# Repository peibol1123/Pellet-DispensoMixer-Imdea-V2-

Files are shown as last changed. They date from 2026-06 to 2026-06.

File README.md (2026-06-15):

# Pellet DispensoMixer V2

Developed at IMDEA Materials Institute.

<p align="center">
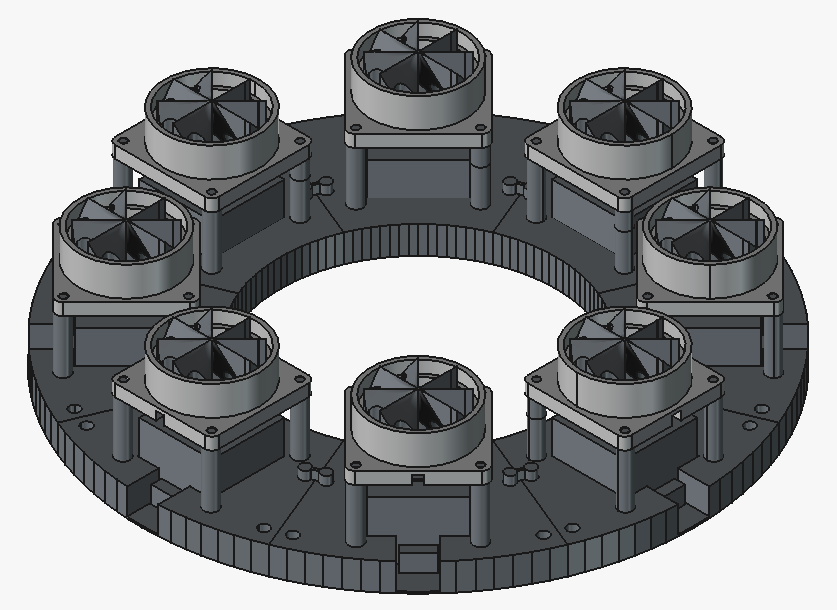
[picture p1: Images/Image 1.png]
  
</p>

## Project Overview

The Pellet DispensoMixer V2 is an updated and improved version of the original Pellet DispensoMixer developed at IMDEA. The main objective of this redesign was to increase system reliability, simplify assembly and maintenance procedures, and improve the overall integration of the platform.

The new version replaces the previous actuation system with NEMA 17 stepper motors and consolidates the electronic architecture into a single control board, reducing wiring complexity and improving maintainability.

This repository contains the complete design package generated during the development of the project, including CAD models, manufacturing files, electrical schematics, and supporting documentation.

## Key Features

- NEMA 17 stepper motor actuation.
- Single integrated control PCB: BIGTREETECH Octopus V1.1
- Modular and maintainable mechanical architecture.
- Complete CAD documentation.
- Manufacturing-ready 3D models.
- Electrical schematics and wiring documentation.
- Improved assembly workflow.
- Open and editable design files.

## Improvements Over the Original Pellet DispensoMixer

This project represents a significant redesign of the original Pellet DispensoMixer platform.

| Feature | Original Version | V2 |
|---|---|---|
| Actuation System | 28BYJ-48 unipolar geared stepper motor | NEMA 17 stepper motors |
| Electronics | 8x Arduino UNO | Single integrated PCB |
| Assembly | More complex integration | Tool-free cascade assembly with vertically stacked components and sequential insertion |
| Reliability | Baseline performance | Improved robustness |

## Bill of Materials

| Component | Quantity |
|---|---|
| NEMA 17 Stepper Motor | 8 |
| A4988 Stepper Motor Driver | 8 |
| BTT Octopus Pro Main Control Board | 1 |
| Power Supply | 1 |
| 3D Printed Components |  |
| Feed Ramp | 8 |
| Module Coupling Pin | 8 |
| Rotor Mount | 8 |
| Rotor | 8 |
| Structural Frame | 8 |
## Repository Structure

```text
CAD/
├── Assembly/
  ├── FreeCAD/
  ├── STEP/
├── Parts/
  ├── FreeCAD/
  ├── STEP/

Electronics/
├── Schematics/
├── PCB/
└── Wiring/

Images/
├── FinalAssembly.png
└── PrototypePhotos/

Documentation/
└── AdditionalFiles/
```
## Assembly Instructions

The Pellet DispensoMixer V2 follows a screwless cascade assembly method. Each module is inserted vertically on top of the previous component, using the geometry of the base to guide the assembly.

The motor module is first positioned onto the base structure. The upper rotor mount is then inserted above the motor, aligning the central shaft and the surrounding guide columns. Finally, the rotor is aligned on top of the cylindrical chamber and inserted onto the motor shaft.
<p align="center">
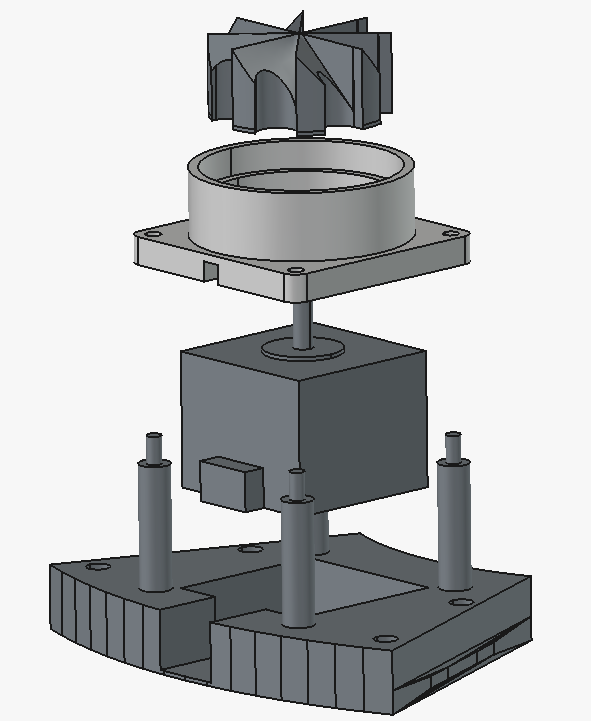
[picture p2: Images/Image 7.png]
  
</p>
Module-to-module alignment is achieved through a locating pin.
<p align="center">
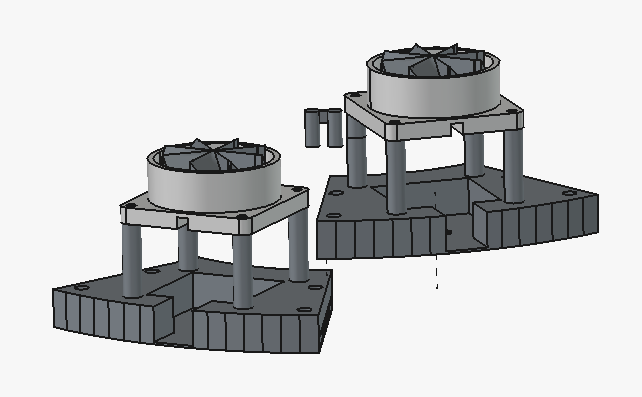
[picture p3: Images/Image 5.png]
  
</p>
This approach reduces the need for additional fasteners, simplifies the assembly process, and makes the system easier to disassemble, inspect, and maintain.

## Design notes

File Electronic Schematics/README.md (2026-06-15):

# Electronic Schematics

This folder contains the electronic wiring documentation for the Pellet DispensoMixer V2.

The electronic system is based on a **BIGTREETECH Octopus Pro V1.1** main control board, **A4988 stepper motor drivers**, **NEMA 17 stepper motors**, an external power supply, and an **ST-LINK/V2** programmer for SWD programming.

The objective of this documentation is to make the electronic assembly easier to reproduce, inspect, modify, and maintain.

---

## Main Components

| Component | Function |
| --- | --- |
| BIGTREETECH Octopus Pro V1.1 | Main control board |
| A4988 stepper motor drivers  | Motor driver modules |
| NEMA 17 stepper motors | Actuation of the dispensing modules |
| External power supply | Power input for the control board and motors |
| ST-LINK/V2 | SWD programming and debugging interface |

---

## Electronics Connections
### System Architecture

The electronics are centralized around the **BIGTREETECH Octopus Pro V1.1**, which acts as the main control board for the complete dispensing system.

```text
Power Supply
      │
      ▼
BIGTREETECH Octopus Pro V1.1
      │
      ├── A4988 Driver 1 ── NEMA 17 Motor 1
      ├── A4988 Driver 2 ── NEMA 17 Motor 2
      ├── A4988 Driver 3 ── NEMA 17 Motor 3
      ├── A4988 Driver 4 ── NEMA 17 Motor 4
      ├── A4988 Driver 5 ── NEMA 17 Motor 5
      ├── A4988 Driver 6 ── NEMA 17 Motor 6
      ├── A4988 Driver 7 ── NEMA 17 Motor 7
      └── A4988 Driver 8 ── NEMA 17 Motor 8
```

This architecture simplifies the wiring compared with the previous version of the system, since all motor control is handled from a single main board.

### Power Connection

The external power supply is connected to the main power input of the Octopus Pro board.

| Power Supply | Octopus Pro Connection |
| --- | --- |
| Positive output | `POWER +` / `VIN +` |
| Negative output | `POWER -` / `GND` |

Before powering the system, check:

* Correct polarity of the power input.
* Correct voltage level for the board and motor drivers.
* Correct motor power jumper configuration.
* No loose wires or accidental short circuits.

Do not power the board if the polarity or voltage configuration is uncertain.

### Stepper Driver and Stepper Motor Installation

Each motor has two internal coils. Before connecting the motors, identify the coil pairs using a multimeter in continuity mode.

Each **A4988 stepper motor driver** is inserted into one of the driver sockets of the Octopus Pro board.
<p align="center">
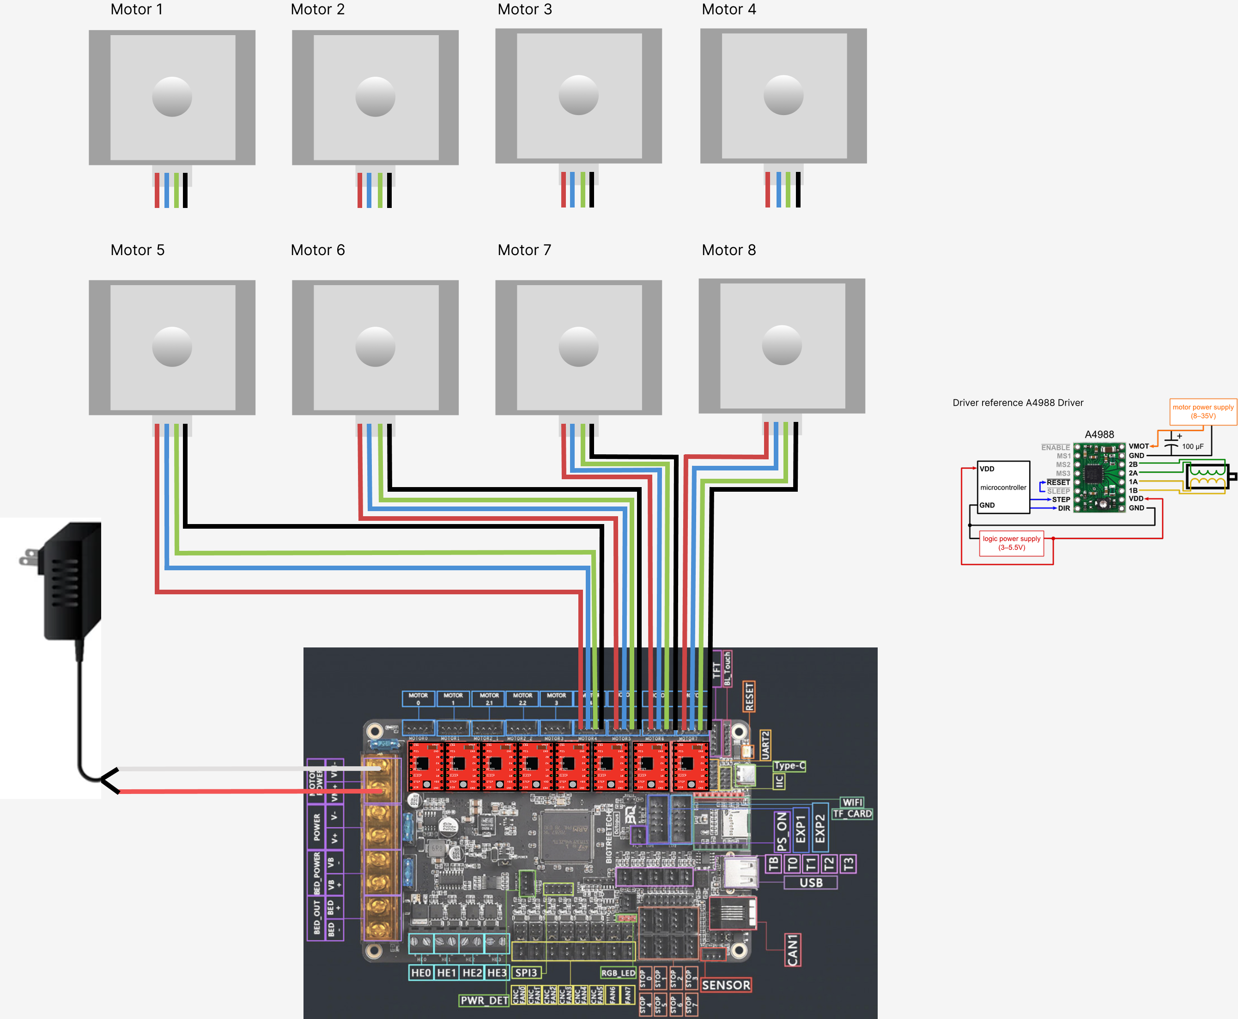
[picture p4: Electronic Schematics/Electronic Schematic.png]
Electronic Schematic
  
</p>
Important notes:

* Check the orientation of each A4988 driver before powering the board.
* Do not insert or remove drivers while the board is powered.
* Use heatsinks if the drivers operate for long periods or under high current.
* Adjust the current limit of each driver before continuous operation.

If a motor vibrates but does not rotate, the coil pairs may be incorrectly connected. If the motor rotates in the opposite direction, reverse the motor direction in firmware or swap one coil pair.

Do not connect or disconnect stepper motors while the board is powered

---

## ST-LINK/V2 Programming Connection

Before connecting the ST-LINK/V2 programmer, make sure that the required USB drivers are installed on the host computer.
The official ST-LINK drivers can be downloaded from [STMicroelectronics](https://www.st.com/en/development-tools/stsw-link009.html):

It is also recommended to install  [STM32CubeProgrammer](https://www.st.com/en/development-tools/stm32cubeprog.html), which provides the required tools for firmware upload, device detection, memory inspection, and debugging, however the firmware is gonna upload through Arduino Ide:

The following image provides a reference for the ST-LINK/V2 pinout.
<p align="center">
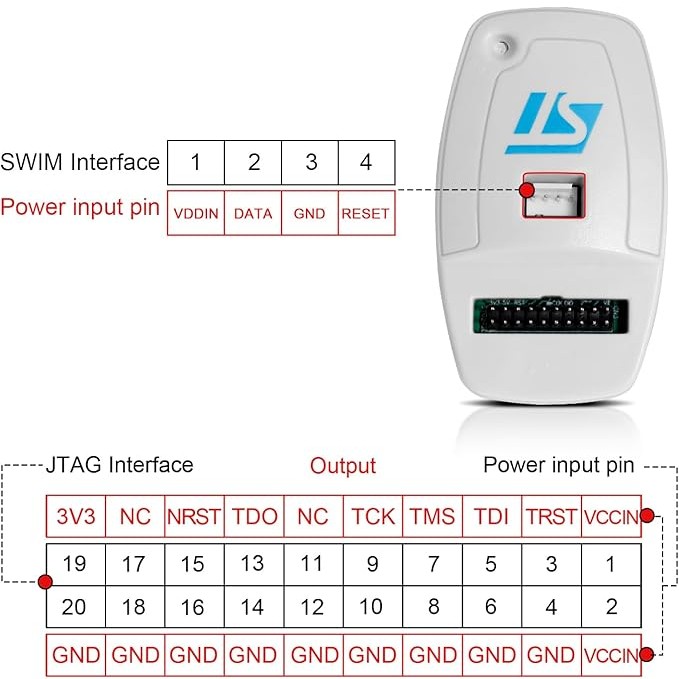
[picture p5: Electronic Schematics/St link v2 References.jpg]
ST Link V2 References
  
</p>
Recommended ST-LINK/V2 to Octopus Pro connection:

| ST-LINK/V2 20-pin Connector | Signal | Octopus Pro SWD Connector |
| --- | --- | --- |
| Pin 1 | `VCCIN` / target voltage reference | `3V3` |
| Pin 7 | `TMS` / `SWDIO` | `SWDIO` |
| Pin 9 | `TCK` / `SWCLK` | `SWCLK` |
| Pin 15 | `NRST` | `RST` |
| Pin 4 or any GND pin | `GND` | `GND` |

The `RST` connection is optional for basic SWD communication, but it is recommended because it allows the programmer to connect using hardware reset if needed.

The following image provides a reference for the BIGTREETECH Octopus Pro V1.1 pinout.
<p align="center">
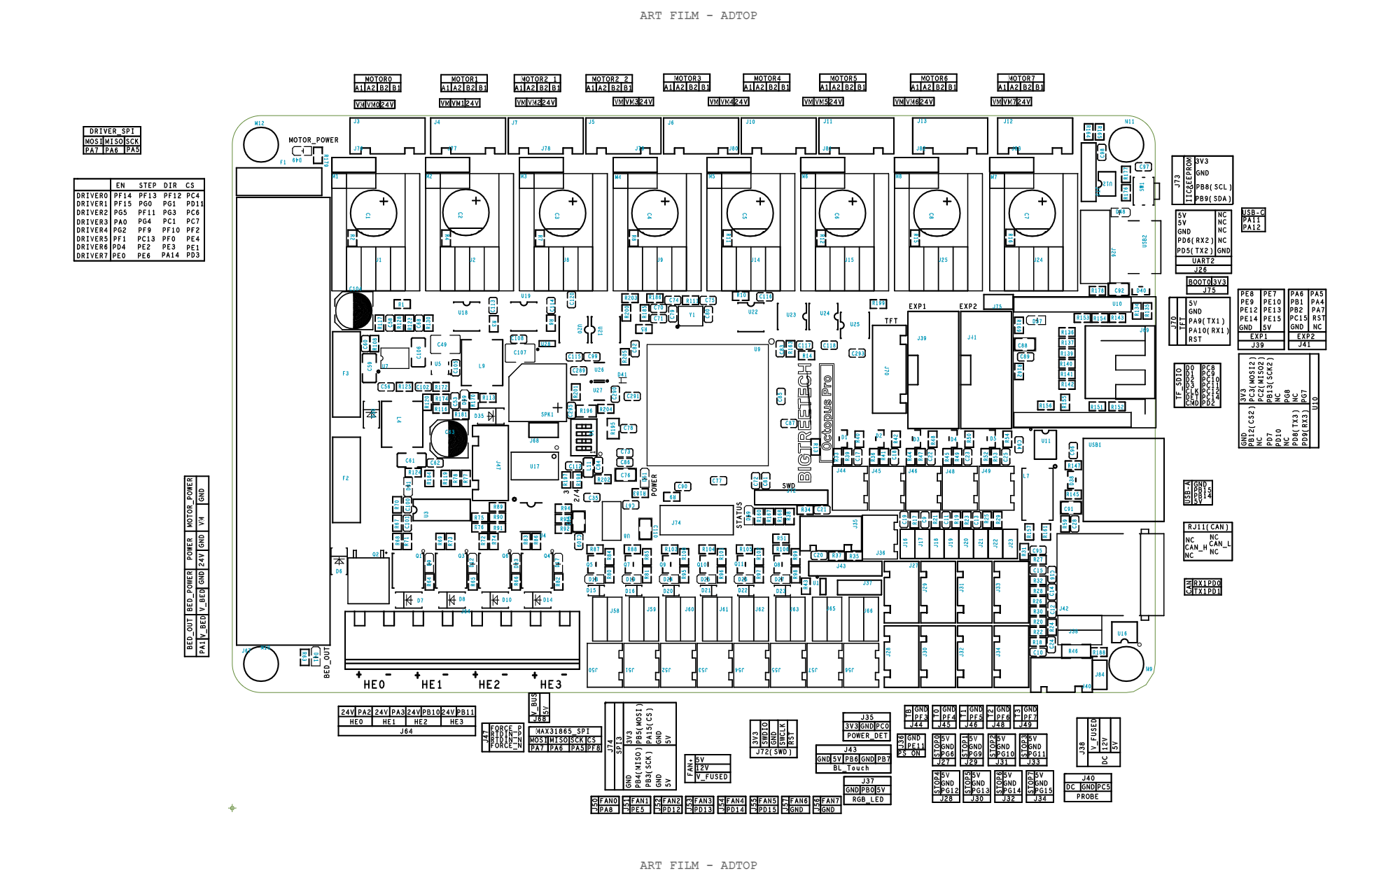
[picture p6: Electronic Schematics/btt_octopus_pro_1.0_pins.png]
BTT Octopus Pro V1.1 Pinout
  
</p>

## Suggested Cable Color Code

| Signal | Recommended Color |
| --- | --- |
| `3V3` / voltage reference | Red |
| `GND` | Brown |
| `SWDIO` | Orange |
| `SWCLK` | Yellow |
| `RST` | Green |

The following figure is provided as a reference for the wiring configuration.
<p align="center">
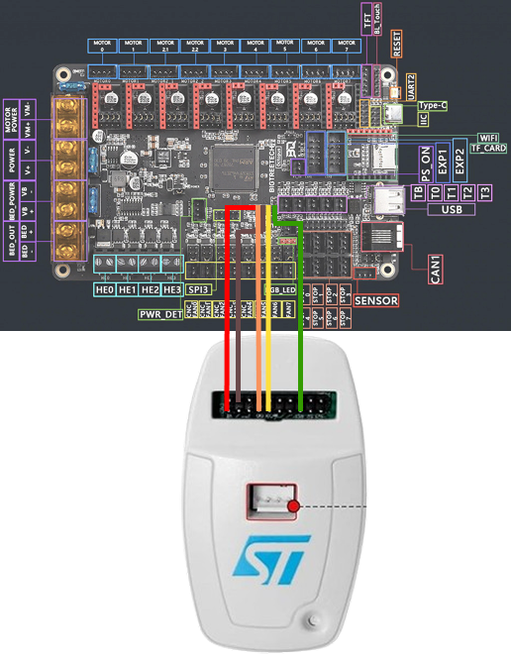
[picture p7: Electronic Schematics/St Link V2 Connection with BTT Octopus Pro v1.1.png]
ST-LINK V2 Connection with BTT Octopus Pro V1.1
  
</p>
---

## Electronics Assembly Procedure

1. Verify that the Octopus Pro board is powered off.
2. Insert the A4988 stepper motor drivers into the driver sockets.
3. Check the orientation of every A4988 driver.
4. Connect each NEMA 17 motor to its corresponding motor output.
5. Verify the coil pairs of each motor before powering the system.
6. Connect the external power supply to the Octopus Pro power input.
7. Connect the ST-LINK/V2 to the SWD connector if firmware programming is required.
8. Power the board and verify that no driver overheats.
9. Test each motor individually before running the full dispensing sequence.
10. If a motor moves in the wrong direction, correct the direction in firmware or swap one coil pair.

---

## Safety Notes

* Always disconnect power before modifying the wiring.
* Do not connect or disconnect motors while the board is powered.
* Do not insert or remove stepper drivers while the board is powered.
* Check the current limit of each A4988 driver before long operation.
* Verify power supply voltage and polarity before testing.
* Keep the board on a non-conductive surface during initial tests.
* If any component becomes excessively hot, power off the system immediately.

---

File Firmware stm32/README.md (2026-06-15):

# Firmware Compilation and Upload

This folder contains the firmware documentation for the Pellet DispensoMixer V2.

The firmware is compiled and uploaded using the **Arduino IDE**. The system is based on the **BIGTREETECH Octopus Pro V1.1** control board, which uses an STM32 microcontroller. For the initial board connection and firmware upload, an **ST-LINK/V2** programmer can be used through the SWD interface.

---

A detailed tutorial on configuring and programming STM32 microcontrollers with STM32Duino can be found in the following blog post:

[Luis Llamas – Programming STM32 with Arduino IDE and a USB-TTL Converter](https://www.luisllamas.es/programar-stm32-con-ide-de-arduino-y-conversor-usb-ttl/)

---

## Required Software

Before compiling or uploading the firmware, install the following software:

| Software | Purpose |
| --- | --- |
| Arduino IDE | Firmware development, compilation, and upload |
| STM32 MCU board package | STM32 board support inside Arduino IDE |
| ST-LINK/V2 drivers | Required for the computer to detect the ST-LINK programmer |
| STM32CubeProgrammer | Required for STM32 firmware upload and device detection |

The official ST-LINK/V2 drivers can be downloaded from [STMicroelectronics](https://www.st.com/en/development-tools/stsw-link009.html).

STM32CubeProgrammer can also be downloaded from [STMicroelectronics](https://www.st.com/en/development-tools/stm32cubeprog.html).

The Arduino IDE can be downloaded from [Arduino](https://www.arduino.cc/en/software).

---

## Installing STM32 Support in Arduino IDE

1. Open the Arduino IDE.
2. Go to:

```text
File → Preferences
```

3. In **Additional Boards Manager URLs**, add the following URL:

```text
https://github.com/stm32duino/BoardManagerFiles/raw/main/package_stmicroelectronics_index.json
```

4. Then go to:

```text
Tools → Board → Boards Manager
```

5. Search for:

```text
STM32 MCU based boards
```

6. Install the STM32 board package.

---

---

## ST-LINK/V2 Connection

The ST-LINK/V2 is used to connect to the STM32 microcontroller through the SWD interface.

The SWD wiring documentation is available in:

```text
Electronics Schematics/
```

## Compiling the Firmware

To compile the firmware in Arduino IDE:

```text
Sketch → Verify/Compile
```

or press:

```text
Ctrl + R
```

If the compilation is successful, the Arduino IDE will generate the firmware binary without errors.

---

## Uploading the Firmware Through Arduino IDE

To upload the firmware:

1. Connect the ST-LINK/V2 to the computer.
2. Connect the ST-LINK/V2 to the SWD connector of the Octopus Pro V1.1.
3. Power the Octopus Pro board using USB-C or the external power supply.
4. Open the firmware project in Arduino IDE.
5. Select the correct STM32 board configuration.
6. Select the upload method: St Link v2

After the upload is complete, the board should restart and run the uploaded firmware.

---

## Firmware Upload Workflow

```text
Install ST-LINK/V2 drivers
        ↓
Install STM32CubeProgrammer
        ↓
Install STM32 board package in Arduino IDE
        ↓
Open firmware in Arduino IDE
        ↓
Select STM32 board configuration
        ↓
Connect ST-LINK/V2 through SWD
        ↓
Compile firmware
        ↓
Upload firmware from Arduino IDE
```

---

## Troubleshooting

### The ST-LINK/V2 is not detected

Check that:

* The ST-LINK/V2 drivers are installed.
* The USB cable is working.
* The ST-LINK/V2 appears correctly in the device manager.
* STM32CubeProgrammer can detect the programmer.

### The board is not detected

Check that:

* The Octopus Pro board is powered.
* `3V3`, `GND`, `SWDIO`, and `SWCLK` are correctly connected.
* The SWD cable order is correct.
* A lower SWD frequency is selected.
* The `RST` wire is connected if using hardware reset.

### Upload fails

Check that:

* The correct board is selected in Arduino IDE.
* The selected upload method is `STM32CubeProgrammer (SWD)`.
* STM32CubeProgrammer is installed.
* The ST-LINK/V2 drivers are correctly installed.
* The board is not shorted or incorrectly powered.

### Compilation errors

Check that:

* The STM32 board package is installed.
* All required libraries are installed.
* The firmware files are in the correct folder.
* The selected board matches the STM32 microcontroller used by the Octopus Pro V1.1.

---

## Safety Notes

* Do not connect or disconnect wiring while the board is powered.
* Do not connect 5 V to the SWD connector.
* Verify the polarity of the external power supply before powering the board.
* Keep the board on a non-conductive surface during testing.
* If any component overheats, disconnect power immediately.
* Always verify the wiring before uploading or running the firmware.

---

## Notes

The Pellet DispensoMixer V2 firmware is developed and uploaded using the Arduino IDE. The ST-LINK/V2 programmer is used for SWD communication with the STM32 microcontroller, especially during initial configuration, firmware upload, or debugging.

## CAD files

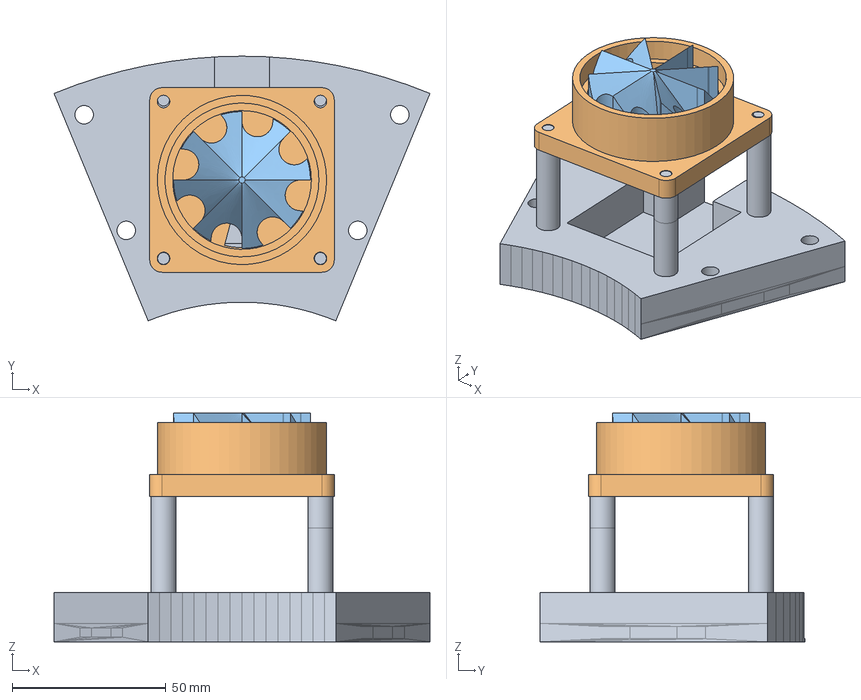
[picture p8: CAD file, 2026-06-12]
Pellet Dispensomixer V2 CAD/Assembly/Module SubAssembly/Module Pellet Dispensomixer V2.FCStd
122.2 x 86.0 x 74.3 mm
Structural Frame_001
Rotor Mount_001
Rotor_002

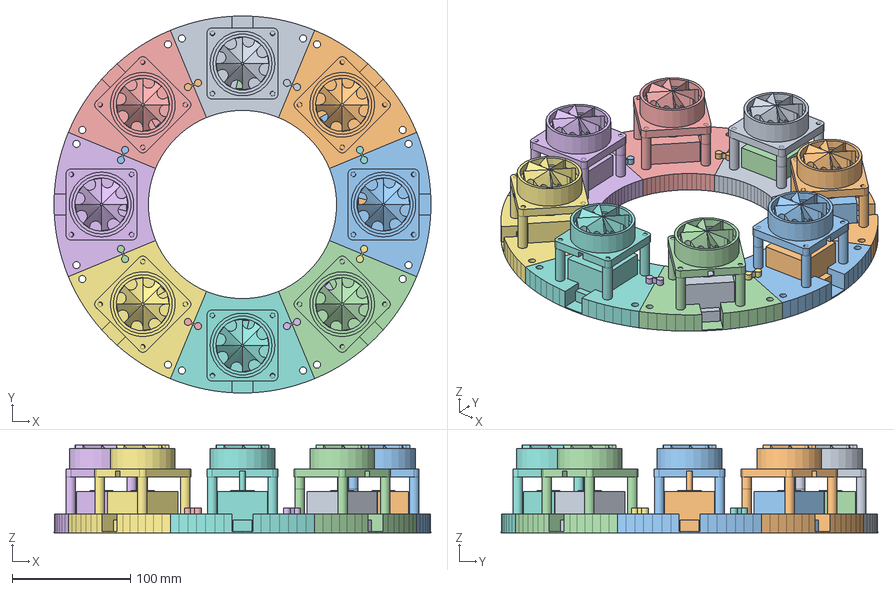
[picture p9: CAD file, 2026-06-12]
Pellet Dispensomixer V2 CAD/Assembly/Pellet Dispensomixer V2.FCStd
319.4 x 319.4 x 74.3 mm
Module Pellet Dispensomixer V2_001
Module Pellet Dispensomixer V2_003
Module Pellet Dispensomixer V2_004
Module Pellet Dispensomixer V2_006
Module Pellet Dispensomixer V2_007
Module Pellet Dispensomixer V2_008
Module Pellet Dispensomixer V2_009
Module Pellet Dispensomixer V2_010
Module Coupling Pin_001
Module Coupling Pin_002
Module Coupling Pin_003
Module Coupling Pin_004
Module Coupling Pin_005
Module Coupling Pin_006
Module Coupling Pin_007
Module Coupling Pin_008
Nema 17_003
Nema 17_004
Nema 17_005
Nema 17_006
Nema 17_007
Nema 17_008
Nema 17_009
Nema 17_010

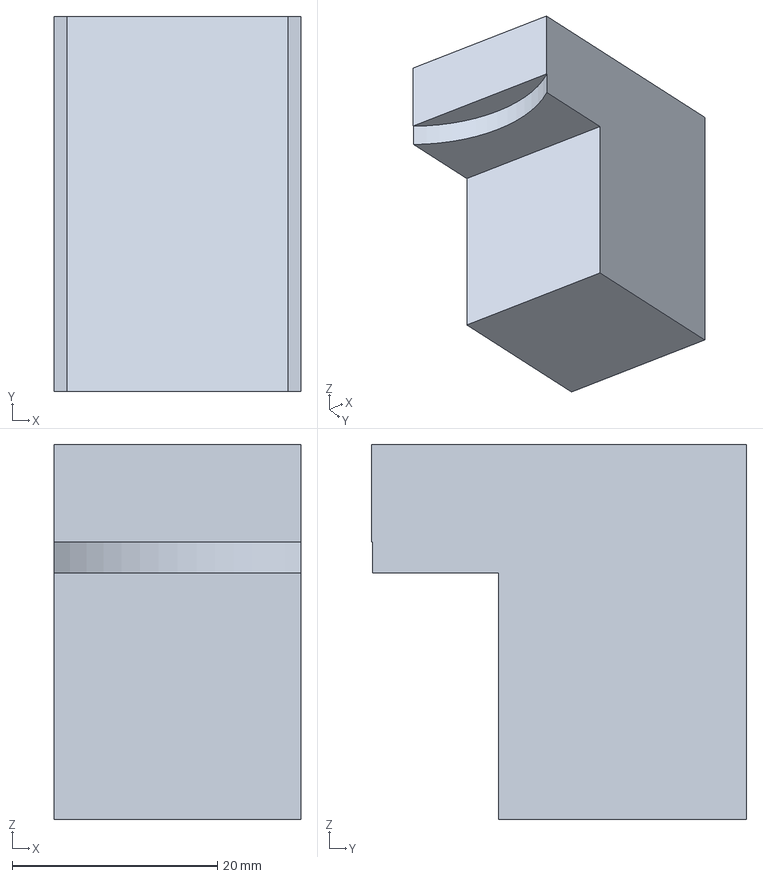
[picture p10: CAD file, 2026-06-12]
Pellet Dispensomixer V2 CAD/Parts/Feed Ramp/Feed Ramp.FCStd
24.0 x 36.5 x 36.5 mm

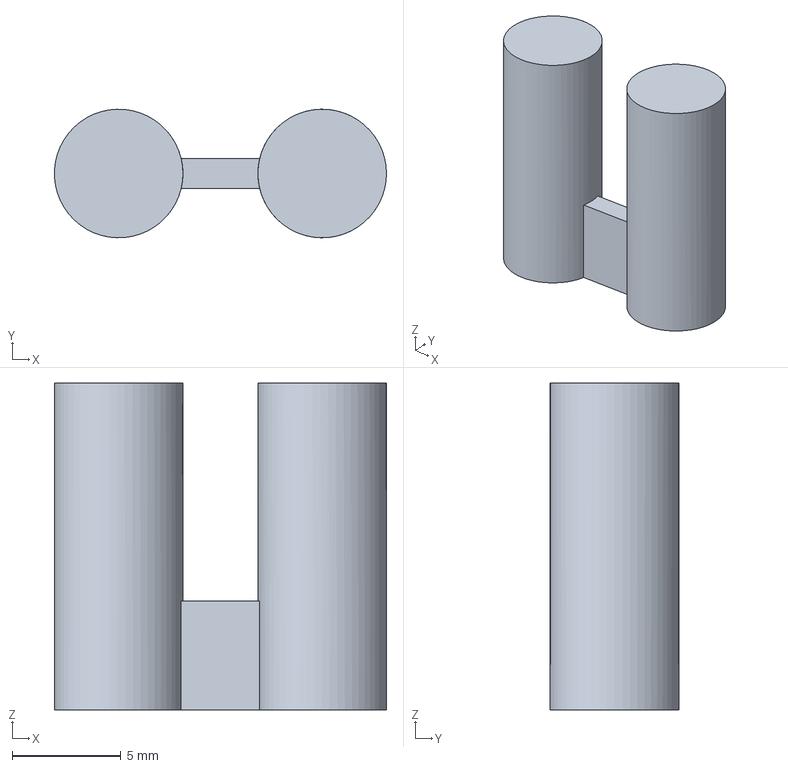
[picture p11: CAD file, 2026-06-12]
Pellet Dispensomixer V2 CAD/Parts/Module Coupling Pin/Module Coupling Pin.FCStd
15.2 x 5.90 x 15.0 mm

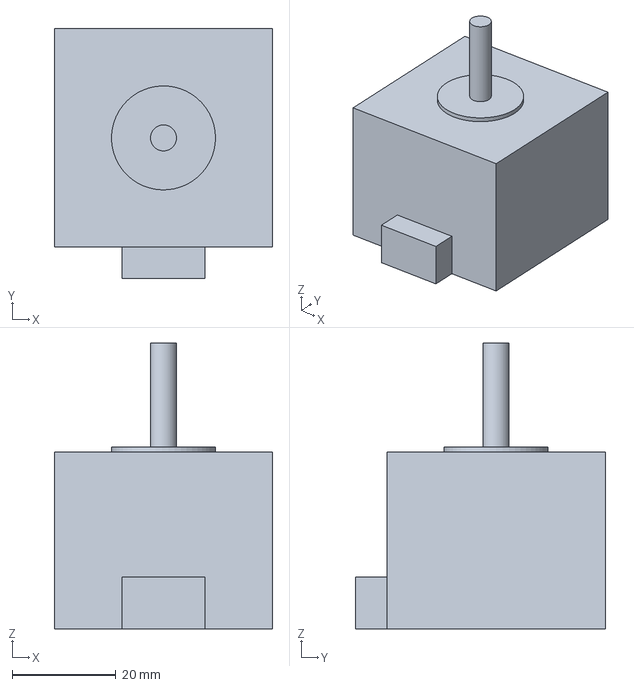
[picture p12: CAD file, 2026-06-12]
Pellet Dispensomixer V2 CAD/Parts/Nema 17 (standard measures)/Nema 17.FCStd
42.0 x 48.0 x 55.0 mm

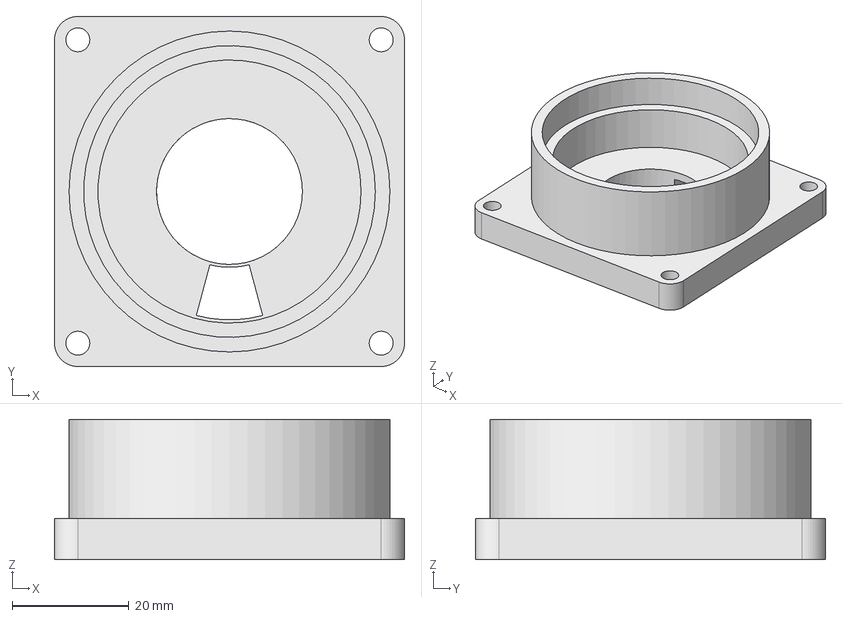
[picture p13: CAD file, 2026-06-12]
Pellet Dispensomixer V2 CAD/Parts/Rotor Mount/Rotor Mount STEP.step
60.0 x 60.0 x 24.0 mm

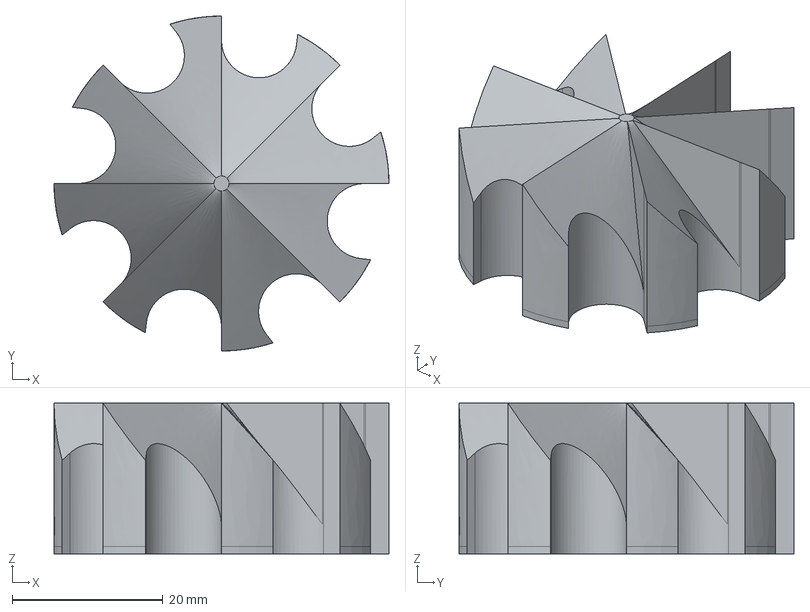
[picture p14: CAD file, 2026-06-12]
Pellet Dispensomixer V2 CAD/Parts/Rotor/Rotor STEP.step
44.5 x 44.5 x 20.0 mm

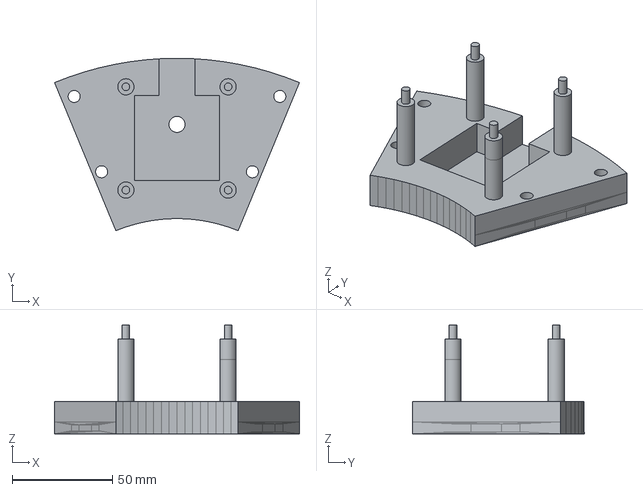
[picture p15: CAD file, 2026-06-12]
Pellet Dispensomixer V2 CAD/Parts/Structural Frame/Structural Frame STEP.step
122.2 x 86.0 x 54.2 mm

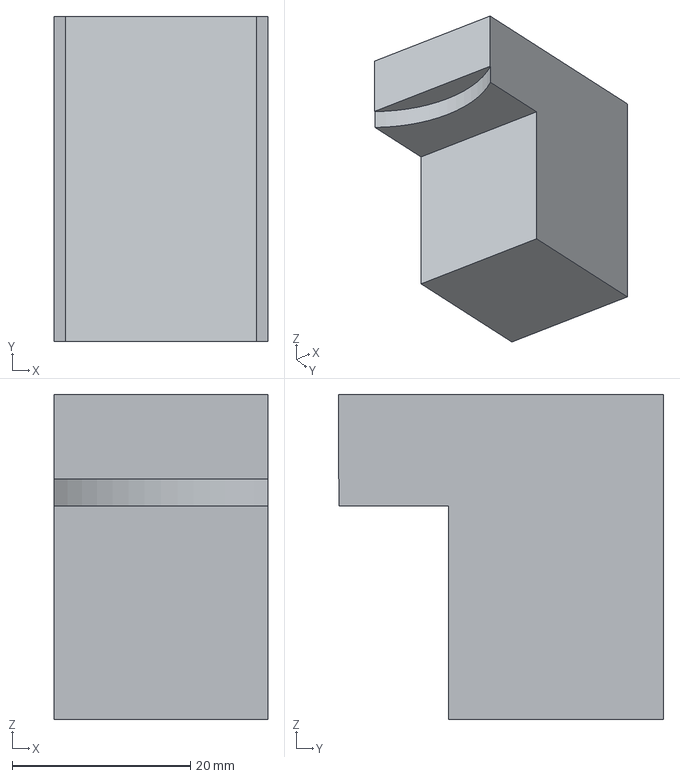
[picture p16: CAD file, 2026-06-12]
Pellet Dispensomixer V2 CAD/Parts/Feed Ramp/Feed Ramp STEP.step
24.0 x 36.5 x 36.5 mm

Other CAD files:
Pellet Dispensomixer V2 CAD/Assembly/Module SubAssembly/Module Pellet Dispensomixer STEP.step
Pellet Dispensomixer V2 CAD/Parts/Module Coupling Pin/Module Coupling Pin STEP.step
Pellet Dispensomixer V2 CAD/Parts/Rotor Mount/Rotor Mount.FCStd
Pellet Dispensomixer V2 CAD/Parts/Rotor/Rotor.FCStd
Pellet Dispensomixer V2 CAD/Parts/Structural Frame/Structural Frame.FCStd

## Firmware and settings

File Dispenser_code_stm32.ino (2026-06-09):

#include <AccelStepper.h>

/*
  Adaptación para BIGTREETECH Octopus Pro v1.1 usando STM32duino.

  Notas importantes:
  - Este código usa los sockets de drivers M0-M7 de la Octopus Pro.
  - Los antiguos "sleepPin" del código original se sustituyen por ENABLE.
  - En drivers tipo TMC2209 / TMC5160 / A4988 / DRV8825, ENABLE suele ser activo en LOW.
  - Comando por Serial:
      '0' -> activa Motor 1 / socket M0
      '1' -> activa Motor 2 / socket M1
      ...
      '7' -> activa Motor 8 / socket M7
      '8' o 'x' -> desactiva todos los motores
  - Esta pensado para ser compilado y subido mediante un clon St-Link V2
*/

constexpr uint8_t NUM_MOTORS = 8;
constexpr int NO_ACTIVE_MOTOR = 8;

// Parámetros originales
constexpr long shakeSteps = 50;
constexpr int strokes = 3;
constexpr long dispenseStepIncrement = 15;
constexpr int dispenseDiscretizations = 30;

constexpr float shakeAcceleration = 2500.0;
constexpr float dispenseAcceleration = 1000.0;

constexpr float shakeMaxSpeed = 1000.0;
constexpr float dispenseMaxSpeed = 300.0;

// Pulso mínimo STEP. 2 us suele ser más seguro para drivers tipo TMC/A4988/DRV8825.
constexpr unsigned int minStepPulseWidthUs = 2;

// -----------------------------------------------------------------------------
// Pines BTT Octopus Pro v1.1, (diferencia en el EN del Driver3 con respecto a V1: PA0 --> PA2)
// -----------------------------------------------------------------------------

// STEP pins: M0, M1, M2, M3, M4, M5, M6, M7
const uint8_t motorStepPins[NUM_MOTORS] = {
  PF13,  // Motor 1 -> M0 STEP
  PG0,   // Motor 2 -> M1 STEP
  PF11,  // Motor 3 -> M2 STEP
  PG4,   // Motor 4 -> M3 STEP
  PF9,   // Motor 5 -> M4 STEP
  PC13,  // Motor 6 -> M5 STEP
  PE2,   // Motor 7 -> M6 STEP
  PE6    // Motor 8 -> M7 STEP
};

// DIR pins: M0, M1, M2, M3, M4, M5, M6, M7
const uint8_t motorDirPins[NUM_MOTORS] = {
  PF12,  // Motor 1 -> M0 DIR
  PG1,   // Motor 2 -> M1 DIR
  PG3,   // Motor 3 -> M2 DIR
  PC1,   // Motor 4 -> M3 DIR
  PF10,  // Motor 5 -> M4 DIR
  PF0,   // Motor 6 -> M5 DIR
  PE3,   // Motor 7 -> M6 DIR
  PA14   // Motor 8 -> M7 DIR
};

// ENABLE pins: M0, M1, M2, M3, M4, M5, M6, M7
const uint8_t motorEnablePins[NUM_MOTORS] = {
  PF14,  // Motor 1 -> M0 ENABLE
  PF15,  // Motor 2 -> M1 ENABLE
  PG5,   // Motor 3 -> M2 ENABLE
  PA2,   // Motor 4 -> M3 ENABLE. Ojo: en Octopus Pro v1.1 es PA2, en la referencia es PA0, si no funciona probar PA0
  PG2,   // Motor 5 -> M4 ENABLE
  PF1,   // Motor 6 -> M5 ENABLE
  PD4,   // Motor 7 -> M6 ENABLE
  PE0    // Motor 8 -> M7 ENABLE
};

// ENABLE activo en LOW
constexpr uint8_t DRIVER_ENABLE_STATE = LOW;
constexpr uint8_t DRIVER_DISABLE_STATE = HIGH;

// -----------------------------------------------------------------------------
// Objetos AccelStepper
// -----------------------------------------------------------------------------

AccelStepper steppers[NUM_MOTORS] = {
  AccelStepper(AccelStepper::DRIVER, motorStepPins[0], motorDirPins[0]),
  AccelStepper(AccelStepper::DRIVER, motorStepPins[1], motorDirPins[1]),
  AccelStepper(AccelStepper::DRIVER, motorStepPins[2], motorDirPins[2]),
  AccelStepper(AccelStepper::DRIVER, motorStepPins[3], motorDirPins[3]),
  AccelStepper(AccelStepper::DRIVER, motorStepPins[4], motorDirPins[4]),
  AccelStepper(AccelStepper::DRIVER, motorStepPins[5], motorDirPins[5]),
  AccelStepper(AccelStepper::DRIVER, motorStepPins[6], motorDirPins[6]),
  AccelStepper(AccelStepper::DRIVER, motorStepPins[7], motorDirPins[7])
};

int activeMotor = NO_ACTIVE_MOTOR;

// -----------------------------------------------------------------------------
// Funciones auxiliares
// -----------------------------------------------------------------------------

void setMotorEnabled(uint8_t motorIndex, bool enabled) {
  if (motorIndex >= NUM_MOTORS) {
    return;
  }

  digitalWrite(
    motorEnablePins[motorIndex],
    enabled ? DRIVER_ENABLE_STATE : DRIVER_DISABLE_STATE
  );
}

void disableAllMotors() {
  for (uint8_t i = 0; i < NUM_MOTORS; i++) {
    setMotorEnabled(i, false);
  }
}

void enableOnlyMotor(uint8_t motorIndex) {
  for (uint8_t i = 0; i < NUM_MOTORS; i++) {
    setMotorEnabled(i, i == motorIndex);
  }
}

void readSerialCommand() {
  while (Serial.available() > 0) {
    char command = (char)Serial.read();

    if (command == '\n' || command == '\r' || command == ' ') { //funcion para los saltos de linea, revisar
      continue;
    }

    // Selección de motor: '0' a '7'
    if (command >= '0' && command <= '7') {
      activeMotor = command - '0';

      enableOnlyMotor((uint8_t)activeMotor);

      Serial.print("Active motor index: ");
      Serial.println(activeMotor);
      Serial.print("Octopus socket: M");
      Serial.println(activeMotor);

      return;
    }

    // Desactivar todos
    if (command == '8' || command == 'x' || command == 'X') {
      activeMotor = NO_ACTIVE_MOTOR;
      disableAllMotors();

      Serial.println("All motors disabled.");
      return;
    }

    Serial.print("Ignored command: ");
    Serial.println(command);
  }
}

void runDispenserCycle(uint8_t motorIndex) {
  if (motorIndex >= NUM_MOTORS) {
    return;
  }

  AccelStepper &motor = steppers[motorIndex];

  // Shake
  motor.setMaxSpeed(shakeMaxSpeed);
  motor.setAcceleration(shakeAcceleration);

  // Mantengo tu lógica original: j <= strokes.
  // Con strokes = 3, esto ejecuta 4 ciclos.
  for (int j = 0; j <= strokes; j++) {
    if (!Serial.available()) {
      motor.move(shakeSteps);
      motor.runToPosition();
    } else {
      return;
    }

    if (!Serial.available()) {
      motor.move(-shakeSteps);
      motor.runToPosition();
    } else {
      return;
    }
  }

  // Dispense
  motor.setMaxSpeed(dispenseMaxSpeed);
  motor.setAcceleration(dispenseAcceleration);

  // Mantengo tu lógica original: j <= dispenseDiscretizations.
  // Con dispenseDiscretizations = 30, ejecuta 31 incrementos.
  for (int j = 0; j <= dispenseDiscretizations; j++) {
    if (!Serial.available()) {
      motor.move(dispenseStepIncrement);
      motor.runToPosition();
    } else {
      return;
    }
  }
}

// -----------------------------------------------------------------------------
// Setup / Loop
// -----------------------------------------------------------------------------

void setup() {
  Serial.begin(9600);

  // Si usas USB CDC, esto da un pequeño margen para abrir el puerto serie.
  // Si no hay USB conectado, no bloquea indefinidamente.
  unsigned long startTime = millis();
  while (!Serial && (millis() - startTime < 2000)) {
    // Espera máxima de 2 segundos
  }

  for (uint8_t i = 0; i < NUM_MOTORS; i++) {
    pinMode(motorStepPins[i], OUTPUT);
    pinMode(motorDirPins[i], OUTPUT);
    pinMode(motorEnablePins[i], OUTPUT);

    // Seguridad: todos los motores desactivados al arrancar
    digitalWrite(motorEnablePins[i], DRIVER_DISABLE_STATE);

    steppers[i].setMaxSpeed(dispenseMaxSpeed);
    steppers[i].setAcceleration(dispenseAcceleration);
    steppers[i].setMinPulseWidth(minStepPulseWidthUs);
  }

  activeMotor = NO_ACTIVE_MOTOR;

  Serial.println("BTT Octopus Pro v1.1 dispenser controller ready.");
  Serial.println("Send 0-7 to select motor M0-M7.");
  Serial.println("Send 8 or x to disable all motors.");
}

void loop() {
  readSerialCommand();

  if (activeMotor != NO_ACTIVE_MOTOR) {
    runDispenserCycle((uint8_t)activeMotor);
  }
}

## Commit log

2026-06-09 Add Arduino STM32 dispenser firmware
    Initial upload of the Arduino firmware for the Pellet Dispensomixer V2 project
2026-06-12 Add CAD parts and assembly files
    Added the complete CAD folder including assembly, parts, and exported 3D model files.
    [Feed Ramp STEP.step, Feed Ramp.FCStd, Module Coupling Pin STEP.step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]
